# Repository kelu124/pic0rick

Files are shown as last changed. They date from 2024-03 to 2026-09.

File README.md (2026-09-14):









# the _pic0rick_ project




The pic0rick is a very central board for an ultrasound pulse-echo system. It is composed of a main board, based on the RP2040 (or RP2350) and easy to solder SMD, to which a single, and a double PMOD connector can connect to addons:

* The main board is equipped with a 60Msps, 10bit ADC. Front end is protected against high-voltage pulses, and features a proven time-gain compensation system consisting in a AD8331 (7.5 dB to 55.5dB) with a controlling (MCP4812) SPI DAC.
* The single PMOD connector can plug to the Pulser board, which can be equipped with a simple +-25V generation board. Together, they generate the pulse on behalf of the pic0rick main board. The setup can generate three-level pulses ( with a pair of MD1210 + TC6320 ).
* The double PMOD connector can be used for virtually anything. The current code allows for a VGA to be connected, which displays acquisitions from the board.

The current system uses both PIOs (one for the acquisition, the other for the VGA) which leaves the other resources of the rp2040 relatively free to use for your own priorities.

Published documents include:
* KiCad design files for the main board
* KiCad design files for the pulser + hv boards
* KiCad design files for the MUX
* KiCad design files for other boards =)
* rp2040/rp2350 firmware for the microcontroller.

I _know_ the PMODs aren't strictly speaking PMODs, I needed to have 5V facility on the header =)

And if you want to discuss the project - [meet us on our chat](https://matrix.to/#/!dEbJSiragnEvzVBdUa:matrix.org?via=matrix.org).

# Repository layout

| Path | Contents |
|---|---|
| `firmware/` | The unified RP2040/RP2350 firmware (CMake project `adc-pulse`). One source tree with `-DMUX` / `-DDSP` build options. `hw/` = shared acquisition + pulser + spi1 DAC; `dsp/` = RP2350 DSP (CMSIS-DSP Hilbert envelope + binary protocol); `max/` = MAX14866 mux. `version.yaml` + `CHANGELOG.md` track the firmware version; `build.sh` builds all 6 variants into `dist/`. |
| `python/` | Host stack (`pic0rick` package): `device.py` (serial driver), `dsp.py` (binary frame protocol), `ndt_acquisition.py` (echo/thickness analysis + HDF5), and the `example_*.ipynb` notebooks. |
| `hardware/` | KiCad design files and `build.sh` fabrication outputs — main board (`adc/`), pulser + HV (`pulser/`), MUX (`mux/`), VGA (`vga/`), PSRAM (`psram/`). |
| `docs/` | Documentation: `dsp_output_formats.md`, `dsp_test_guide.md`, `images/`, `data/`, `fw_history/` (maintainer-curated reference `.uf2` baselines), and `claude/` (cross-session engineering notes). |
| `.github/workflows/` | CI: builds all firmware variants and publishes a release on push to `main`. |

# Getting Started

## Prerequisites

* pic0rick main board + pulser board + HV board (assembled)
* USB-C cable
* Python 3.9+
* A piezoelectric transducer (e.g. 5 MHz single-element contact probe)

## Building the firmware

The firmware is a single source tree (`firmware/`) with build options:

- **`-DMUX`** (default on) — MAX14866 HV multiplexer support.
- **`-DDSP`** (RP2350/`pico2` only) — on-board Hilbert-envelope DSP + binary
  protocol (see [DSP build](#dsp-build-rp2350) below).

```bash
cd firmware && ./build.sh          # builds all 6 variants into firmware/dist/:
#   rp2040-{mux,nomux}, rp2350-{mux,nomux}, rp2350-{mux,nomux}-dsp
```

Prebuilt `firmware/rp2040.uf2` / `firmware/rp2350.uf2` are the default (mux,
non-DSP) builds. CI publishes all variants as release assets.

## Flashing the firmware

1. Hold the **BOOTSEL** button on the RP2040/RP2350 while connecting USB — the board mounts as a USB mass-storage device. *(After the first flash you can instead send the `reboot-dfu` command over serial to re-enter the bootloader without the button.)*
2. Copy the compiled `.uf2` file into the drive. The board reboots automatically.
3. Verify: open a serial terminal at 115,200 baud. You should see the `run>` prompt (stdio build). Send `version` to confirm the firmware version, board and options.

## Installing the Python library

```bash
pip install pyserial numpy h5py scipy matplotlib
```

Clone this repo and add `python/` to your path, or run notebooks from the `python/` directory.

## Quick start

The examples below target the **DSP build** (`-DDSP`, RP2350) — the recommended
firmware, which streams CRC-checked binary frames. For the plain **stdio build**
see [Serial commands](#serial-commands-stdio--non-dsp-build).

```python
from pic0rick.device import Pic0rick
from pic0rick.ndt_acquisition import UltrasonicAcquisition

probe = Pic0rick()           # auto-detects the USB serial port
print(probe.version()['raw'])

# Set TGC gain (raw DAC value 0–1023; higher = more gain)
probe.set_gain(300)

# Configure and arm the pulser so the capture transmits
probe.configure_pulse(negative_ns=200, damp_ns=2000, positive_ns=200,
                      order="pos-first")
probe.arm_pulser()

frame = probe.read_raw()     # 8000-sample raw ADC frame (CRC-checked)
signal = frame.samples()     # numpy uint16, 0..1023
# envelope = probe.read_fft().samples()   # 4096-sample Hilbert envelope
probe.disarm_pulser()
```

> On the **stdio (non-DSP)** build instead use `probe.dac(gain)`,
> `probe.pulse_adc_trigger(pon, poff, damp)`, `probe.read()`.

Or use the higher-level acquisition wrapper (drives the DSP build for you):

```python
acq = UltrasonicAcquisition.from_probe(
    Fech=60e6,
    pon=70,        # pulse-on duration [ns]
    poff=70,       # pulse-off duration [ns]
    damp=6000,     # damping duration [ns]
    gain=300,      # raw DAC value (0–1023)
    target="1018 steel 25 mm",
    h5_path="my_scan.h5",
)
acq.plot()
```

## Serial commands (stdio / non-DSP build)

The stdio build exposes a text protocol at 115,200 baud (USB CDC), with a `run>`
prompt:

| Command | Arguments | Description |
|---|---|---|
| `start acq <pon> <poff> <damp>` | nanoseconds | Fire pulse, DMA-capture 8000 samples |
| `write dac <N>` | 0–1023 | Set TGC gain (MCP4812 10-bit DAC) |
| `read` | — | Return last captured buffer (hex, comma-separated 10-bit values) |
| `write mux <hex>` | hex word | Write the MAX14866 shift register *(MUX builds)* |
| `set mux` / `clear mux` | — | Pulse the MAX14866 SET / CLR line *(MUX builds)* |
| `version` | — | Print firmware version, board/chip, options, git hash, release URL |
| `reboot-dfu` | — | Reboot into the USB bootloader (BOOTSEL) for reflashing |

> The **DSP build** uses different commands (`dac write`, `read_raw`, `read_fft`,
> …) and a binary protocol — see [DSP build](#dsp-build-rp2350).

### Parameter details

**`pon` / `poff` / `damp`** — expressed in **nanoseconds** from Python. The firmware converts them to 125 MHz clock cycles internally (divides by 8).

**`gain`** — raw 10-bit DAC value (0–1023) controlling the VGAIN pin of the AD8331 TGC amplifier (7.5 dB to 55.5 dB range). The example notebook uses values in the 0–500 range.

### DSP build (RP2350)

Building with `-DDSP=ON` (RP2350/`pico2`) adds an on-board DSP path: a float32
CMSIS-DSP Hilbert envelope. Instead of the text REPL it speaks a binary framed
protocol (64-byte header + CRC32) with two capture modes:

- **`read_raw`** — 8000 raw ADC samples (no FFT).
- **`read_fft`** — 4096-sample Hilbert envelope.

plus `acq raw|envelope|alaw`, `stream start|stop`, `dsp scale|selftest`,
`dac write <0..1023>`, `pulse config <neg_ns> <damp_ns> <pos_ns> <neg-first|pos-first>`,
`pulser arm|disarm`, `status`, `help`, `version`, `reboot-dfu`.

Drive it from Python with `pic0rick.dsp` and these `Pic0rick` methods:
`version()`, `status()`, `set_gain(n)`, `configure_pulse(...)`,
`arm_pulser()`/`disarm_pulser()`, `read_raw()`, `read_fft()`, `capture(payload)`.
The frame and status formats are documented in
[`docs/dsp_output_formats.md`](docs/dsp_output_formats.md); see
[`docs/dsp_test_guide.md`](docs/dsp_test_guide.md) and the
`python/example_dsp.ipynb` / `python/example_simple.ipynb` notebooks.

## Signal chain

```
Transducer
   │
   ├──► TX path: PIO pulser GPIO11/12 (P+/P-) + GPIO16/17 (PDAMP/OE) → MD1213 + TC6320 → ±25V three-level pulse
   │
   └──► RX path: T/R protection → AD8331 TGC (gain set by MCP4812 DAC)
                  → 60 Msps 10-bit ADC (PIO + DMA, 8000 samples/acquisition)
                  → USB CDC → Python
```

The ADC samples are 10-bit unsigned (0–1023, mid-scale = 512). The `ndt_acquisition` wrapper normalises them to float32 in the range ≈ [−1, 1]:

```python
signal = (adc_count - 512) / 512.0
```

# Setup

## The three boards assemble look like this

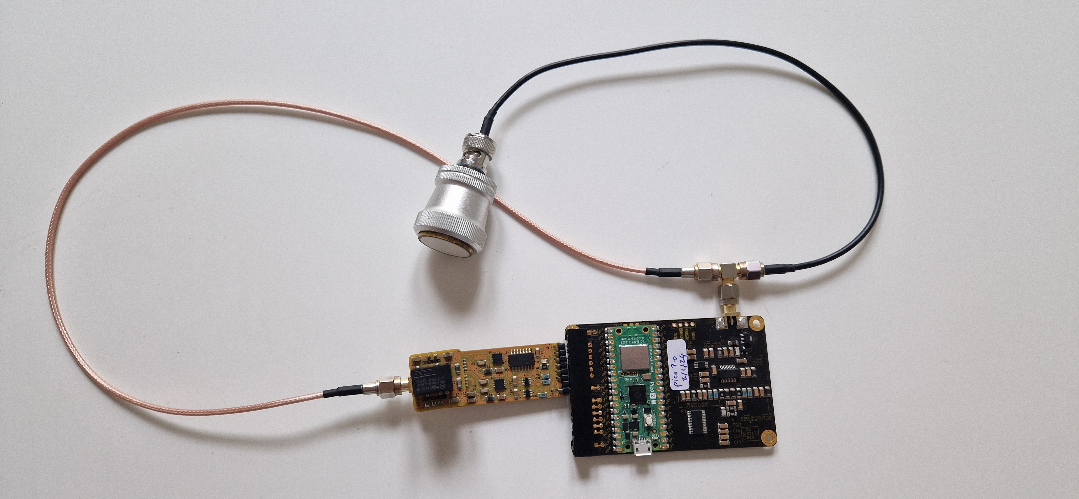
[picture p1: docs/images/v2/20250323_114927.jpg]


## Example of acquisitions

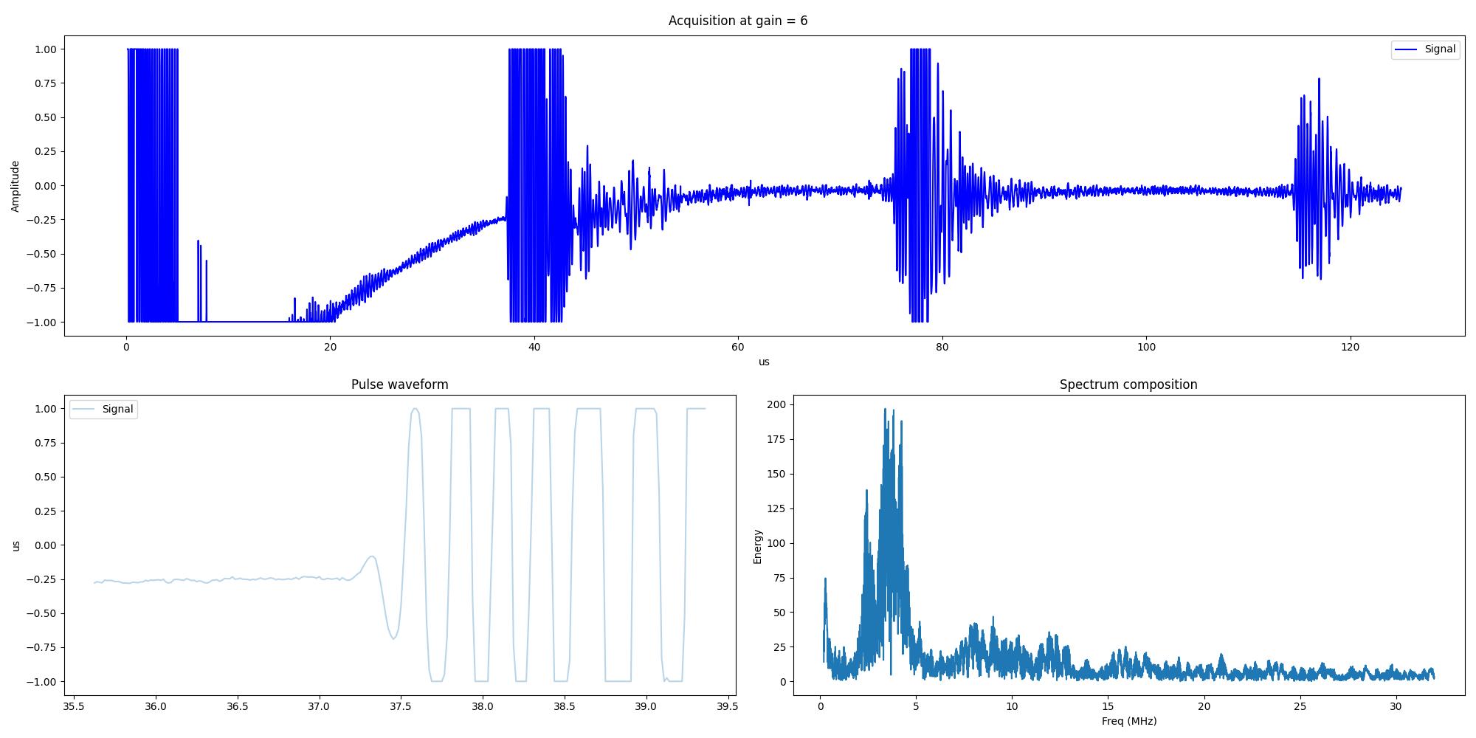
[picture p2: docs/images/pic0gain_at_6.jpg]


## Demo of output to VGA 

Beware. This is not a standard development, more of a proof of concept. It lives on a [separate branch here](https://github.com/kelu124/pic0rick/tree/VGA).

Only using the pico to setup gain and trigger acquisitions. The screen displays the gain value (0 to 9, with a 100x divider). Displays raw buffer of acquisition.

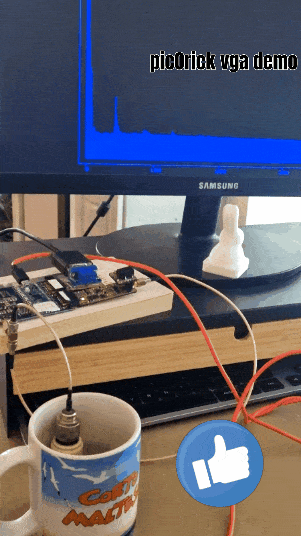
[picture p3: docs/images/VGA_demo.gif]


## Example of a compact assembly 

Within a game card footprint

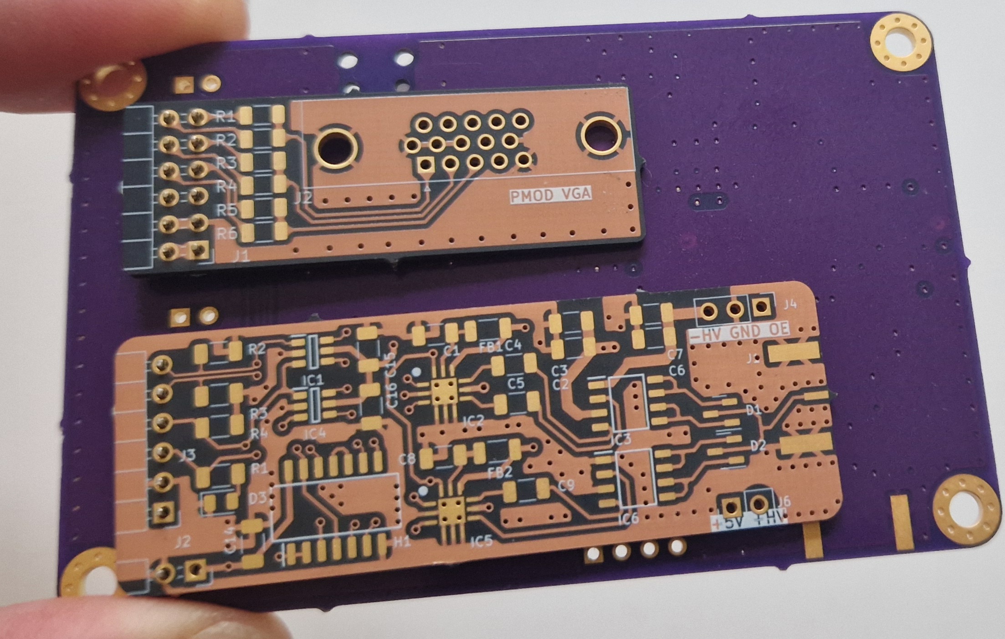
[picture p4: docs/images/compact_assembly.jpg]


# Along with the other boards

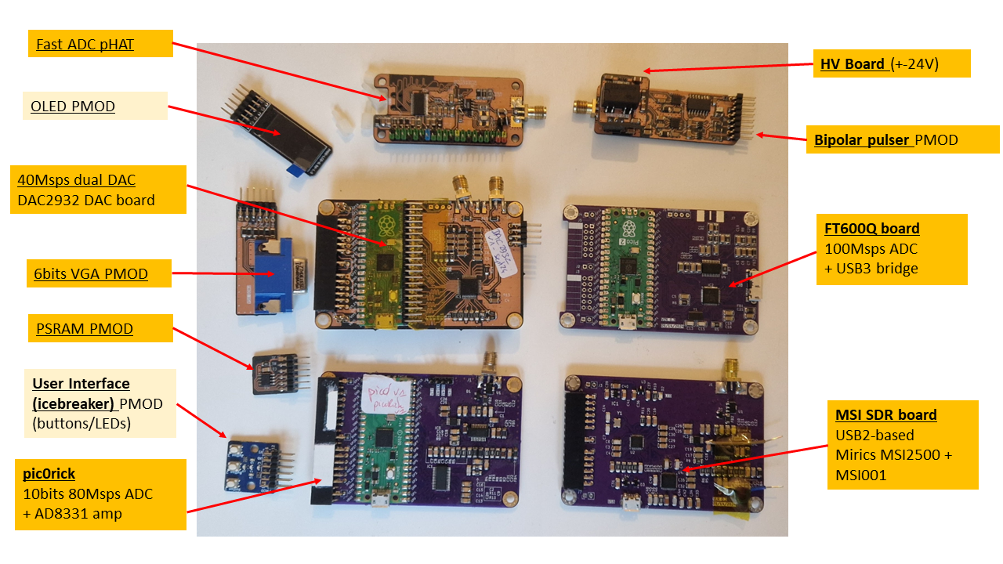
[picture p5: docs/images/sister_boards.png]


# Assembly

## What you get :

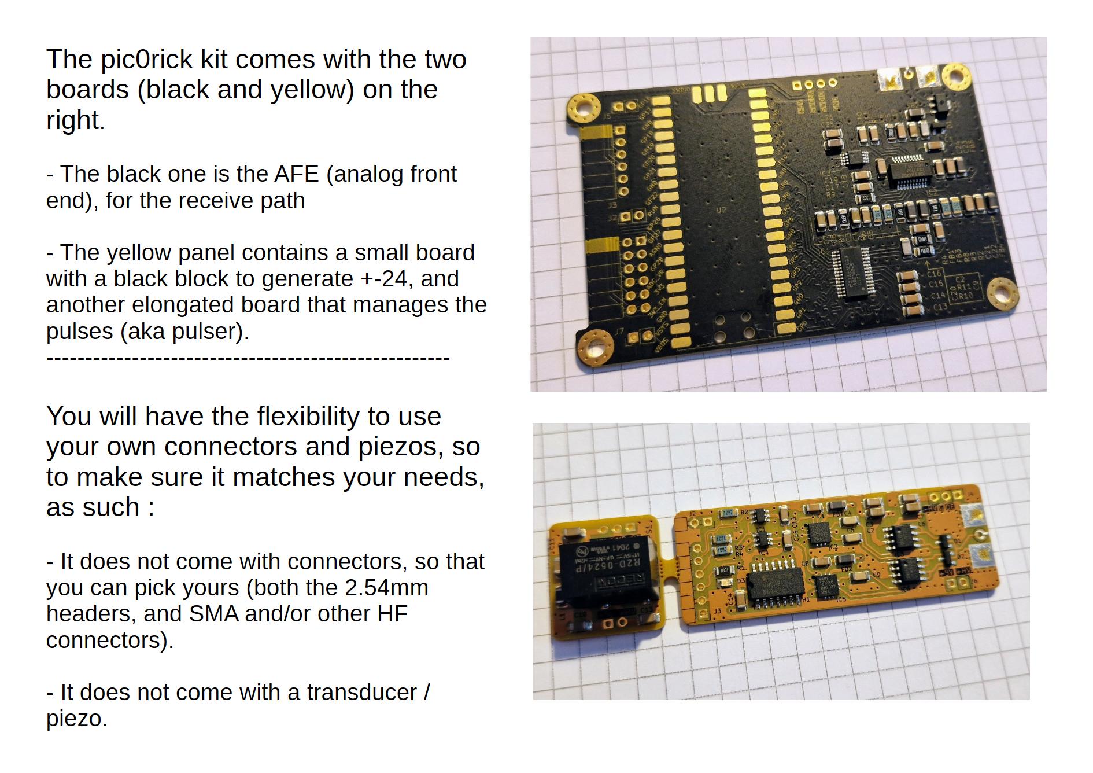
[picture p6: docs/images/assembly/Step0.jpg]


## Before assembly

You will need to get a few headers, a raspberry pico, and SMA connectors

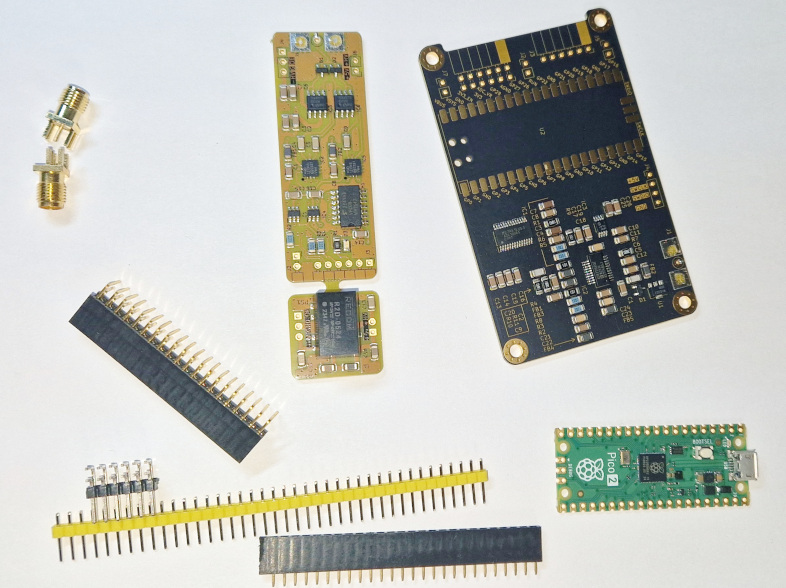
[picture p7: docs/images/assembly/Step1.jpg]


## Focus on the Pulser connector

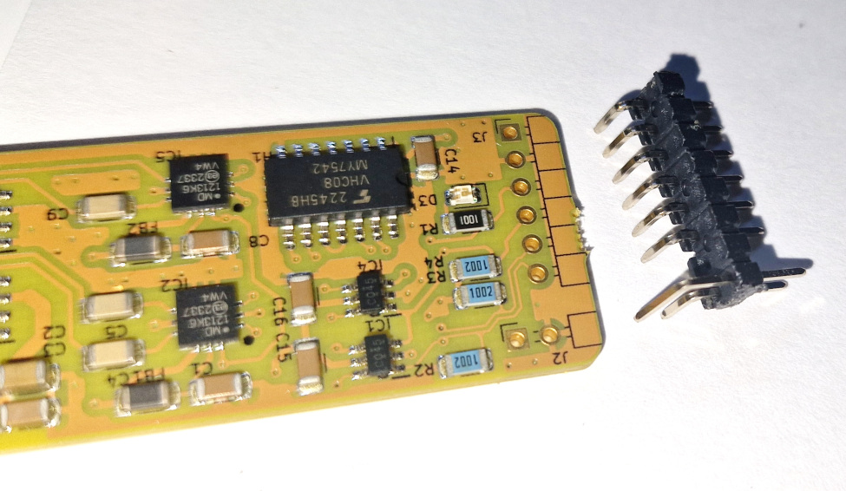
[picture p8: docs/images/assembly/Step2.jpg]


## Once assembled

### Top view

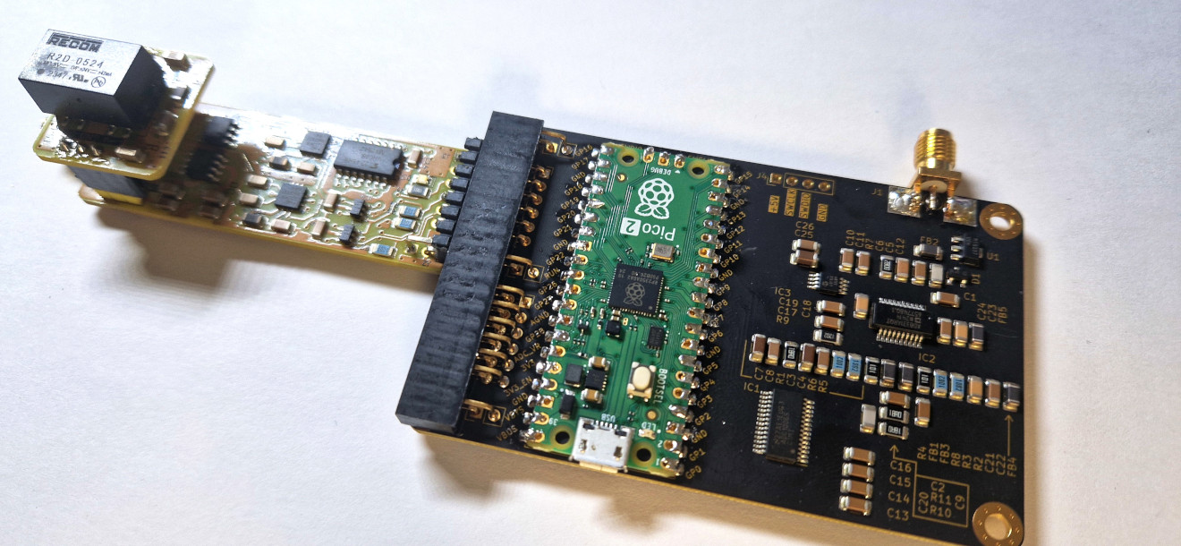
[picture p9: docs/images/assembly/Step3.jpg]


### Bottom view 

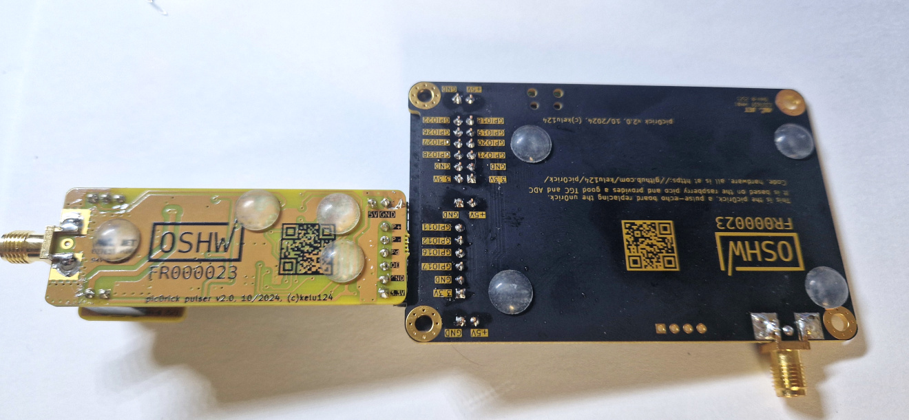
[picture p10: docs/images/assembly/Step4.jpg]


# License

This work is based on three previous TAPR projects, [the echOmods project](https://github.com/kelu124/echomods/), the [un0rick project](https://doi.org/10.5281/zenodo.377054), and the [lit3rick project](https://doi.org/10.5281/zenodo.5792245) - their boards are open hardware and software, developped with open-source elements as much as possible.

Copyright Luc Jonveaux (<kelu124@gmail.com>) 2024

* The hardware is licensed under TAPR Open Hardware License (<www.tapr.org/OHL>)
* The software components are free software: you can redistribute it and/or modify it under the terms of the GNU General Public License as published by the Free Software Foundation, either version 3 of the License, or (at your option) any later version.
* The docs is licensed under a [Creative Commons Attribution-ShareAlike 3.0 Unported License](http://creativecommons.org/licenses/by-sa/3.0/).

## Disclaimer

This project is distributed WITHOUT ANY EXPRESS OR IMPLIED WARRANTY, INCLUDING OF MERCHANTABILITY, SATISFACTORY QUALITY AND FITNESS FOR A PARTICULAR PURPOSE.

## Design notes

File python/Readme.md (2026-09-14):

# pic0rick — Python host tools

Host-side Python for driving a pic0rick over USB serial and turning its raw
ADC traces into ultrasonic NDT (non-destructive testing) measurements: pulse
tuning, gain sweeps, back-wall echo detection, thickness estimation, and HDF5
storage.

> Works with both firmware builds from `firmware/`:
> - the **stdio (non-DSP)** build's text REPL (`write dac`, `start acq`, `read`),
>   used by `Pic0rick.dac/pulse_adc_trigger/read`;
> - the **DSP (`-DDSP`, RP2350)** build's binary frame protocol, via
>   `pic0rick.dsp` and `Pic0rick.status/capture/read_fft/read_raw`.

## Layout

```
python/
├── pic0rick/
│   ├── device.py            # Pic0rick — serial driver for the board
│   └── ndt_acquisition.py   # UltrasonicAcquisition — capture + analysis + HDF5
├── example_acquisition.ipynb  # live-hardware workflow (needs a board)
└── example_process.ipynb      # offline analysis of a saved HDF5 (no hardware)
```

## Python modules

### `pic0rick/device.py` — the hardware driver
`Pic0rick` opens the CDC serial port (115200 baud; `_find_port()` auto-detects
`/dev/ttyACM*`·`/dev/ttyUSB*` on Linux, `COM*` on Windows, `tty.usbmodem*` on
macOS) and wraps the firmware's three text commands:

| Method | Firmware command | Purpose |
|---|---|---|
| `dac(N)` | `write dac N` | Set the DAC (drives the analog gain / VGA). |
| `pulse_adc_trigger(pon, poff, damp)` | `start acq …` | Fire the pulser and capture a trace. |
| `read()` | `read` | Return the captured samples (comma-separated hex text). |

`Fech = 60e6` (60 MS/s) is stored on the instance. `verbose`/`logging` options
echo or append the raw serial exchange to a log file.

### `pic0rick/ndt_acquisition.py` — capture + analysis + storage
The workhorse. Importing `pic0rick.device` is **lazy** (via `get_probe()`), so
this module is fully usable for offline analysis on a machine with no hardware.

- **`UltrasonicAcquisition`** — a dataclass bundling one trace with its metadata
  (`Fech`, `pon/poff/damp`, `gain`, `target`, transducer `piezo_*`). Key members:
  - `from_probe(...)` — trigger the board (`dac` → `pulse_adc_trigger` → `read`),
    decode the hex samples to a normalized `[-1, 1]` signal (`(code-512)/512`),
    and optionally cache to HDF5 keyed on `(gain, pon, poff, damp, target,
    piezo_id)` (a cache hit skips the hardware).
  - `signal_filtered` — zero-phase Butterworth band-pass around the probe's
    centre frequency/bandwidth.
  - `detect_echoes(...)` — rectify + smooth, find the main echo in a time
    window, then track periodic back-wall echoes at `Δt = 2·thickness/c`;
    returns peak times/amplitudes, a measured `Δt`, a back-computed thickness,
    and a labelled figure.
  - `calibrate(...)` — sweep `pon = poff`, save every shot, and report the pulse
    width that maximises the windowed echo amplitude (with a 3-panel figure).
  - `amplitude(...)`, `plot(...)`, `label(...)`, `info(h5_path)`.
- **HDF5 I/O** — `save_h5`, `load_h5`, and per-acquisition `save()`; each trace
  is a group with the signal dataset (gzip) plus scalar attributes, deduplicated
  by the same key.

## Notebooks

### `example_acquisition.ipynb` — live hardware
End-to-end workflow against a connected board and a 1018-steel 5-step
calibration block with a 5 MHz probe: gain sweeps, `calibrate()` for the best
`pon/poff`, then `from_probe()` + `detect_echoes()` at several block thicknesses
(10/15/25 mm) to recover thickness from the echo train, and `info()` to
summarize the stored HDF5.

### `example_process.ipynb` — offline analysis
No hardware: `load_h5(...)` a saved capture, extract the emitted pulse, and study
it (autocorrelation / side-lobe structure) with NumPy/SciPy. Good starting point
for signal-processing work on existing data.

## Dependencies

`pyserial`, `numpy`, `scipy`, `h5py`, `matplotlib`. (No `requirements.txt` here
yet — install those into your environment.)

## Example data

The notebooks read `../docs/data/calibration_block_5steps_1018steel.h5`.

## Quick start (offline)

```python
from pic0rick.ndt_acquisition import load_h5
acqs = load_h5("../docs/data/calibration_block_5steps_1018steel.h5")
acqs[0].plot()          # raw (+ filtered if piezo_* set)
```

Live capture instead:

```python
from pic0rick.ndt_acquisition import UltrasonicAcquisition
a = UltrasonicAcquisition.from_probe(Fech=60e6, gain=350, pon=70, poff=70, damp=6000,
                                     piezo_central_freq=5e6, piezo_bandwidth=4e6)
a.detect_echoes(start_us=35, end_us=55, target_thickness=0.010, speed_of_sound=5950)
```

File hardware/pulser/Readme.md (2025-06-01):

# Pulser hardware file

This folder contains the newest version of pulser and HV board, with breakbout

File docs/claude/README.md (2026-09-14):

# Claude handoff notes — pic0rick

This folder holds durable, cross-session notes for Claude Code instances working
in this repository. If you are a new instance, **read this first**, then the
topic files listed below. Keep these notes updated when you learn something a
future instance would waste time rediscovering.

- `firmware.md` — the repo-root `firmware/` folder: the original mainline
  `adc-pulse` Pico firmware (uses the MAX14866; RP2040 + RP2350 builds).
- `onboard-dsp-firmware.md` — **retired**: the old `experiments/onboard_dsp/`
  firmware is now the mainline `-DDSP` build (`firmware/dsp` + `firmware/hw`);
  this note is now a pointer to where everything went.
- `dsp_output_formats.md` (in `docs/`, not here) — the DSP binary frame / status
  format reference (moved from onboard_dsp's `understanding_figures.md`).
- `python-host-tools.md` — the repo-root `python/` NDT stack (serial driver +
  echo/thickness analysis + HDF5) that drives the mainline firmware.
- `hardware-build.md` — `hardware/build.sh`: KiBot + kicad-cli production
  outputs (gerbers/CPL/BOM/STEP + 3D renders), build groups incl. the fast
  `fab-fast` path, and the venv/3D-model gotchas.
- `hardware-testing.md` — flashing a connected board (UF2 → BOOTSEL mass storage)
  and talking to the REPL over `/dev/ttyACM0`; the `reboot-dfu` iterate loop.

## `docs/fw_history/` — maintainer-only firmware baselines

`docs/fw_history/` holds known-good reference `.uf2` binaries (regression
baselines). **Claude must never add/copy/build/commit `.uf2` files there** — only
the maintainer curates them. Claude may edit its README and *flash* them for
diagnostics. Claude build output goes to `firmware/dist/` (gitignored) + releases.

## Task tracking & commit logs

- `TODO.md` — open, actionable items (with owner tags). `DONE.md` — completed.
  Move items from one to the other as they finish.
- `commits/` — one log file per commit (`<YYYY-MM-DD>-<slug>.md`) recording what
  changed and why. **Add a log entry for every commit you make in this repo.**
- Any new remark/discovery that needs an action goes in `TODO.md`.

## Versioning rule

Firmware and the Python library each carry `A.B.C` in their own `version.yaml`
(`firmware/version.yaml`, `python/pic0rick/version.yaml`).
- **Claude bumps only the patch (C)** — firmware patch on changes to `firmware/`
  files, python patch on changes to `python/` files (independent). A/B 0-99,
  C 0-999. **The maintainer owns major/minor — never change them.**
- Always update that file's one-line, double-quoted `changes:` summary; the CI
  release body and the firmware `version` command read it.
- **On every firmware version bump, add a matching entry to
  `firmware/CHANGELOG.md`** (`## A.B.C — YYYY-MM-DD`, newest first). `version.yaml`
  and `CHANGELOG.md` are the version record — editing only those does not trigger
  a bump.

> These are working memories, not authoritative docs. Verify a claim against the
> code before relying on it — file/line references can drift.

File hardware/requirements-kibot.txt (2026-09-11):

# KiBot production-output toolchain — pinned dependencies for hardware/.venv-kibot
#
# WHY A SEPARATE VENV?
#   KiCad's Python bindings (`pcbnew`) and `wx` are compiled C-extensions that
#   ship only for the *system* Python (3.10 on this Ubuntu 22.04 box, installed
#   by the `kicad` apt package). The repo's root .venv is Python 3.11 via pyenv,
#   so it can never import pcbnew. KiBot needs pcbnew, hence a dedicated venv.
#
# HOW TO (RE)CREATE IT  (hardware/build.sh does this automatically):
#   cd hardware
#   /usr/bin/python3 -m venv --system-site-packages .venv-kibot
#   #   ^ system Python 3.10  ^ so pcbnew + wx from the kicad apt pkg are visible
#   .venv-kibot/bin/pip install --upgrade pip
#   .venv-kibot/bin/pip install --no-compile -r requirements-kibot.txt
#   #   ^ --no-compile is REQUIRED: KiBot's import-time macro system fails when
#   #     its modules are byte-compiled by pip.
#
# SYSTEM PREREQUISITES (apt):
#   kicad kicad-footprints kicad-symbols kicad-packages3d   # provides kicad-cli + pcbnew + 3D models
#   python3-wxgtk4.0                                         # wx, required by KiBot at startup
#
# NOTE: the schematic PDF is produced with `kicad-cli` directly (see build.sh),
#       not KiBot's KiAuto backend, so no X display / xvfb is needed.

kibot
kiauto                 # KiBot helper backends (kicad2step_do, etc.)
InteractiveHtmlBom     # interactive HTML BOM generator (ibom output)

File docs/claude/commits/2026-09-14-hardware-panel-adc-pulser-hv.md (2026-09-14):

# 2026-09-14 — hardware: register panel_adc_pulser_hv in build.sh

Branch `feature/unify-firmware-dsp`.

## What
- Added `panel_adc_pulser_hv` to the `BOARDS` registry in `hardware/build.sh`
  so `./build.sh all` includes it.
- New board folder `hardware/panel_adc_pulser_hv/` (`3_in_1_Panel.kicad_pcb` +
  `.kicad_sch`, 4-layer: F/B + In1/In2).
- Generated production outputs under
  `hardware/panel_adc_pulser_hv/build_jlcpcb/` (same layout as the other
  boards, which keep their build outputs in git).

## Why
User: include panel_adc_pulser_hv in build.sh and run it.

## Verified
`./build.sh panel_adc_pulser_hv` (group `all`) completed cleanly — schematic
present, so full set built:
- gerbers (4 copper layers, mask, silk, edge cuts, PTH/NPTH drills)
- production `3_in_1_Panel-JLCPCB-gerbers.zip`
- assembly JLCPCB BOM + CPL (CSV)
- docs schematic PDF + interactive iBOM HTML
- 3D STEP + top/bottom PNG renders
KiBot exited 0 (no warnings); both renders succeeded.

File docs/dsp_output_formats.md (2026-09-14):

# Understanding the pic0rick firmware outputs

This note explains every output the RP2350A envelope/A-law firmware produces on
its USB-CDC link, so a human (or the capture tool) can read them without diving
into the C sources. It covers:

1. The two kinds of output (text lines vs. binary frames).
2. The `status` line, field by field.
3. The other text responses (`help`, per-command `OK`, `ERR` codes).
4. The 64-byte binary frame header and payloads.
5. The self-test output.

All field definitions come straight from the firmware: `main.c` (`send_status`,
`send_help`, command handlers), `u4rk.h` (constants), `dsp.c` (DSP stages),
`pipeline.c` (drop accounting) and `protocol.c` (`u4rk_serialize_header`).

---

## 1. Two output channels on one CDC port

The firmware never mixes the two:

- **Text mode** — every reply is a single CRLF-terminated line starting with
  `OK ` or `ERR `. This is what you get for `status`, `help`, `dac`, `pulse`,
  `dsp scale`, and the acknowledgement of `acq` / `stream start`.
- **Binary mode** — after an `acq`/`stream start`/`dsp selftest` is
  acknowledged with an `OK`, the firmware emits one or more fixed-layout
  binary **frames** (64-byte header + payload). No text is interleaved while
  frames are in flight; a stream is closed with `stream stop`, which returns to
  text mode with a final `OK stream stopped drops=N`.

---

## 2. The `status` line

Example (all on one line):

```
OK board=pic0rick package=RP2350A firmware=1.6 dsp_backend=f32-rfft-hilbert
   samples=4096 sample_rate=60000000 pulser=disarmed pulse=96/6000/96/pos-first
   dac=1023 scale=512.000 stream=off/1 drops=0
   stages_us=538/4392/137/4751/1066/689 dsp_us=11579 worst_us=12069
   performance=over-budget envelope_max_rate=50 alaw_max_rate=70 cmsis=1.17.0
```

It is a space-separated list of `key=value` tokens. Field by field:

| Token | Example | Meaning |
|---|---|---|
| `board` | `pic0rick` | Fixed board family string. |
| `package` | `RP2350A` | MCU package this build targets (Pico 2 / RP2350A). Fixed literal. |
| `firmware` | `1.6` | Firmware version (`pico_set_program_version` in `CMakeLists.txt`). The capture tool refuses any other value. |
| `dsp_backend` | `f32-rfft-hilbert` | Envelope algorithm: float32 real-FFT Hilbert transform on the Cortex-M33 FPU. Fixed literal. |
| `samples` | `4096` | Samples per acquisition (`U4RK_SAMPLE_COUNT`). |
| `sample_rate` | `60000000` | ADC sample rate in **Hz** (60 MS/s, `U4RK_SAMPLE_RATE_HZ`). |
| `pulser` | `disarmed` | `armed` or `disarmed`. A capture only fires the pulser when armed. |
| `pulse` | `96/6000/96/pos-first` | Pulser timing: `negative_ns / damp_ns / positive_ns / order`. `order` is `neg-first` or `pos-first`. Durations are the *actual* values after rounding to the 8 ns PIO tick. |
| `dac` | `1023` | Last value written to the MCP4812 DAC (0–1023, 10-bit code). Boots at 0. |
| `scale` | `512.000` | A-law full-scale reference in **ADC counts** (`dsp scale`). Envelope values at/above this map to A-law 255; default 512. |
| `stream` | `off/1` | `state/rate_hz`. `state` is `on` or `off`; `rate_hz` is the last requested stream rate. |
| `drops` | `0` | Cumulative dropped frames since boot (`processing_drops + usb_drops`, see §2.2). |
| `stages_us` | `538/4392/137/4751/1066/689` | Per-stage time of the **last DSP frame**, in **microseconds** (see §2.1). |
| `dsp_us` | `11579` | Total time of the last DSP frame, in µs. |
| `worst_us` | `12069` | Worst-case total DSP time observed, in µs (running maximum in `dsp.c`). |
| `performance` | `over-budget` | `ok` if `worst_us <= 4500`, else `over-budget` (`U4RK_DSP_TARGET_US = 4500`). |
| `envelope_max_rate` | `50` | Max accepted `stream` rate for `envelope`, in Hz. |
| `alaw_max_rate` | `70` | Max accepted `stream` rate for `alaw`, in Hz. |
| `cmsis` | `1.17.0` | CMSIS-DSP library version compiled in. |

> Raw's max stream rate (100 Hz, `U4RK_RAW_MAX_RATE_HZ`) is **not** printed in
> the status line — only `envelope_max_rate` and `alaw_max_rate` are.

### 2.1 The six DSP stages (`stages_us`)

The order is fixed: **`preprocess / forward_fft / mask / inverse_fft / magnitude / alaw`**.
They correspond one-to-one to the blocks in `u4rk_dsp_envelope()`:

| # | Stage | What happens |
|---|---|---|
| 1 | `preprocess` | Unpack the 10-bit ADC samples (`(dma >> 1) & 0x3FF`), compute the DC mean, subtract it. |
| 2 | `forward_fft` | 4096-point float32 real FFT (`arm_rfft_fast_f32`, forward). |
| 3 | `mask` | Build the analytic-signal spectrum: multiply the packed half-spectrum by `-j`. |
| 4 | `inverse_fft` | Inverse real FFT to recover the Hilbert (quadrature) component. |
| 5 | `magnitude` | `sqrt(real² + quadrature²)` per sample → the envelope; also tracks the peak. |
| 6 | `alaw` | A-law compression of the envelope (only for A-law frames; `0` otherwise). |

**Raw and legacy captures skip the FFT entirely** (they only run `preprocess`),
so after a raw/legacy capture the status reports `stages_us=0/0/0/0/0/0`,
`dsp_us=0`, and `worst_us=0`. The values persist from the *last DSP frame*, so a
plain `status` query reflects whatever job most recently completed. `worst_us`
is a running maximum kept inside the envelope backend, so it re-appears (largest
value seen since boot) after the next envelope/A-law frame.

### 2.2 Drop accounting (`drops`)

`drops` is the sum of two cumulative-since-boot counters:

- **processing drops** — a capture could not get a buffer/output slot, a DSP
  result could not be queued, or a frame was discarded during `stream stop` /
  DMA-fault cleanup.
- **USB drops** — a completed frame could not be sent to the host (transfer
  failed, or the CDC session closed with work still queued).

For a healthy stream the acceptance criterion is `drops=0`.

---

## 3. Other text responses

### `help`

One line listing every command (used by the tool to confirm there is **no**
MAX14866/mux command):

```
OK commands=status|help|pulser arm|pulser disarm|pulse config <negative_ns> <damp_ns> <positive_ns> <neg-first|pos-first>|dac write <0..1023>|dsp scale <reference>|dsp selftest|acq <raw|envelope|alaw>|stream start <raw|envelope|alaw> <rate_hz>|stream stop|start acq|read
```

### Per-command `OK` acknowledgements

| Command | Success reply |
|---|---|
| `pulser arm` / `pulser disarm` | `OK pulser armed` / `OK pulser disarmed` |
| `pulse config N D P order` | `OK pulse=N/D/P/order` (actual, tick-rounded values) |
| `dac write V` | `OK dac=V` |
| `dsp scale R` | `OK scale=R` |
| `dsp selftest` | `OK selftest frames=21 cases=7` (then 21 binary frames) |
| `acq <type>` | `OK capture started type=<type>` (then 1 binary frame) |
| `stream start <type> <rate>` | `OK stream started type=<type> rate=<rate>` (then binary frames until `stream stop`) |
| `stream stop` | `OK stream stopped drops=N` (or `OK stream already stopped` if not streaming) |
| `start acq` (legacy) | `OK legacy acquisition started` |
| `read` (legacy) | `OK raw-hex 4096` followed by 4096 comma-separated 3-hex-digit samples |

### `ERR` codes

Failures are `ERR <code> <message>`:

| Code | Meaning |
|---|---|
| `BUSY` | An operation is already in progress (no free buffer / pipeline busy). |
| `ARG` | Malformed arguments (bad type, missing/extra token, bad order keyword). |
| `RANGE` | Value out of range (DAC not 0–1023, scale not in (0, 65535], pulse below the 40 ns floor). |
| `RATE` | Requested stream rate outside `1..max` for that payload type. |
| `DMA` | Acquisition timed out; the pulser is disarmed. |
| `COMMAND` | Unknown command. |
| `LINE` | Command line too long. |
| `NO_DATA` | `read` issued before any acquisition completed. |

---

## 4. Binary frames

Every acquisition/stream/self-test result is a **64-byte little-endian header**
followed by its payload. Layout (from `u4rk_serialize_header`):

| Offset | Size | Field | Notes |
|---:|---:|---|---|
| 0 | 4 | magic | ASCII `P0RK` |
| 4 | 1 | protocol version | `1` |
| 5 | 1 | payload type | `1`=raw, `2`=envelope, `3`=A-law |
| 6 | 2 | flags | bitfield, see below |
| 8 | 4 | sequence | monotonic frame counter |
| 12 | 4 | sample count | `4096` |
| 16 | 4 | sample rate | `60000000` Hz |
| 20 | 4 | payload bytes | `8192` raw / `16384` envelope / `4096` A-law |
| 24 | 8 | capture timestamp | µs since boot (self-test: the case index) |
| 32 | 4 | ADC DC mean | float32, mean of the raw samples |
| 36 | 4 | envelope peak | float32, max envelope amplitude (0 for raw) |
| 40 | 4 | A-law reference | float32, the `scale` used for this frame |
| 44 | 4 | pulse negative_ns | uint32 |
| 48 | 4 | pulse damp_ns | uint32 |
| 52 | 4 | pulse positive_ns | uint32 |
| 56 | 4 | dropped frames | cumulative drops at frame time |
| 60 | 4 | payload CRC32 | IEEE CRC32 of the payload only |

### Payload types

| Type | dtype | Bytes | Content |
|---|---|---|---|
| `1` raw | `uint16` LE | 8192 | 10-bit ADC codes (0–1023). |
| `2` envelope | `float32` LE | 16384 | Hilbert envelope amplitude in ADC counts. |
| `3` A-law | `uint8` | 4096 | A-law-compressed positive envelope (A = 87.6). |

### Flags (offset 6)

| Bit | Name | Meaning |
|---:|---|---|
| 0 | `ALAW_SATURATED` | An A-law sample hit the `scale` ceiling and was clipped. |
| 1 | `PROCESSING_DROP` | At least one processing drop has occurred since boot. |
| 2 | `USB_DROP` | At least one USB drop has occurred since boot. |
| 3 | `SELFTEST` | This frame is a deterministic self-test vector. |
| 4 | `PULSER_ARMED` | The pulser was armed for this capture. |
| 8–15 | self-test case | For self-test frames, the case index (0–6) lives in the high byte. |

So a self-test A-law frame for case 2 (`sinusoid`) that saturated would show
`flags = 0x0209` (`0x0200` case=2, `0x08` SELFTEST, `0x01` ALAW_SATURATED).

---

## 5. Self-test output

`dsp selftest` (or the tool's `--selftest`) emits **21 frames = 7 cases × 3
payload types** (raw, envelope, A-law), in that order per case. The 7 cases are:

| Case | Name | Signal |
|---:|---|---|
| 0 | `zero` | all zero |
| 1 | `dc` | constant 700 |
| 2 | `sinusoid` | 32-cycle sine |
| 3 | `am` | amplitude-modulated tone |
| 4 | `two-bursts` | two windowed bursts |
| 5 | `impulse` | single spike at the midpoint |
| 6 | `clipping` | full-scale square wave |

The PC tool validates each case against `scipy.signal.hilbert` and prints, per
case:

```
sinusoid     nrms=8.389e-08 peak_delta=0 alaw_delta=0
```

- `nrms` — normalized RMS error of the envelope (pass ≤ `1e-4`).
- `peak_delta` — envelope peak-index difference in samples (pass ≤ 1).
- `alaw_delta` — max A-law byte-level difference vs. the reference (pass ≤ 1).

---

## Parsing helpers

The host library `python/pic0rick/dsp.py` parses this protocol:

- `pic0rick.dsp.FrameReader(port).read_frame()` → a `Frame` (header + payload;
  CRC-checked; `.samples()` decodes to a numpy array). Length-agnostic:
  `read_raw` (8000) and `read_fft` (4096) both parse.
- `pic0rick.dsp.parse_status(line)` → a typed `dict` (with `pulse`, `stream`,
  `stages_us` broken out as sub-dicts).
- `pic0rick.dsp.describe_status(line_or_dict)` → a human-readable multi-line
  summary (parameters + per-stage DSP µs times).

From the device driver: `Pic0rick.status()`, `.read_fft()`, `.read_raw()`,
`.capture(payload)` (see `docs/claude/python-host-tools.md`).

> This spec was written for the retired `experiments/onboard_dsp/` firmware; that
> firmware is now the mainline `-DDSP` build (`firmware/dsp` + `firmware/hw`).
> The formats are unchanged except that `sample_count` is now per-mode.

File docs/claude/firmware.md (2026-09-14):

# firmware/ (root) — working notes

Scope: the repo-root **`firmware/`** folder — the **unified** pic0rick Pico
firmware (CMake project `adc-pulse`). One tree with build variants: `-DMUX`
(MAX14866 mux, default on) and `-DDSP` (RP2350 Hilbert-envelope DSP + binary
protocol, off by default). The former `experiments/onboard_dsp/` firmware was
merged in here on 2026-09-13 (see `onboard-dsp-firmware.md`).

## First-glance layout

```
firmware/
├── main.c              # stdio REPL (non-DSP builds) + command dispatch
├── main_dsp.c          # raw-TinyUSB command loop (-DDSP builds)
├── CMakeLists.txt      # project adc-pulse; -DDSP / -DMUX / PICO_BOARD toggles
├── build.sh            # builds all 4 non-DSP variants into dist/
├── version.yaml        # single source of truth for the version
├── hw/                 # SHARED, USB-free drivers (both builds)
│   ├── acquisition.c/.h/.pio   # ADC capture + pulser (u4rk_*)
│   ├── pulser.pio              # 4-pin pulser (P+/P-/PDAMP/OE)
│   ├── dac.c/.h                # spi1 MCP4812 gain DAC (u4rk_dac_*)
│   └── u4rk.h                  # pins, sample counts, protocol structs
├── dsp/                # DSP-only (-DDSP): dsp/pipeline/protocol + raw TinyUSB
│   ├── dsp.c/.h pipeline.c/.h protocol.c/.h
│   └── usb_transport.* usb_descriptors.c tusb_config.h
├── max/                # MAX14866 HV mux driver (SPI bit-bang via PIO)
│   ├── max14866.c / max14866.h / max14866.pio
├── rp2040.uf2 / rp2350.uf2   # prebuilt (mux, non-DSP) defaults
└── build*/ dist/       # build trees / outputs (gitignored)
```

## What it does

USB-CDC serial **text REPL** (via `stdio_usb`, not a raw binary protocol like
onboard_dsp). On boot it waits for a USB connection, inits ADC → DAC → MAX14866,
then loops printing a `run> ` prompt and reading a line. `main.c`'s
`command_list` maps text to handlers:

| Command | Handler | Purpose |
|---|---|---|
| `start acq [pon] [poff] [damp]` | `start_acq_cmd` | Configure+arm shared pulser, capture 8000 samples |
| `read` | `read_cmd` | Dump the captured 8000 ADC samples (hex) |
| `write dac <v>` | `write_dac_cmd` | Write the gain DAC (MCP4812, spi1) |
| `version` | `version_cmd` | Print version, changes, board/chip, mux, git hash, release URL |
| `reboot-dfu` | `reboot_dfu_cmd` | Reboot into the USB bootloader (BOOTSEL) via `reset_usb_boot` |
| `write mux <v>` | `max14866` | Write the MAX14866 mux word *(MUX builds only)* |
| `set mux` | `max14866_set` | MAX14866 SET *(MUX builds only)* |
| `clear mux` | `max14866_clear` | MAX14866 CLEAR *(MUX builds only)* |

Parsing is whitespace `strtok` (command + subcommand + rest-as-args); a missing
arg defaults to `"0"`. Unknown input prints `Unknown command: ...`. Output is
human-oriented `printf` text, not framed binary.

## Key constants

- `hw/u4rk.h`: `U4RK_SAMPLE_COUNT 4096` (FFT), `U4RK_RAW_SAMPLE_COUNT 8000`
  (raw), sample rate 60 MHz; pins: ADC clk 0 / data 1–10, DAC CS/SCK/MOSI
  13/14/15, pulser P+ 11 / P- 12 / PDAMP 16 / OE 17.
- `hw/acquisition.c`: ADC PIO 120 MHz, pulse PIO 125 MHz, 8 ns tick (min 5),
  2 ms DMA timeout.
- `max/max14866.h`: SPI bit-bang pins `DIN 18`, `SCLK 19`, `LE 20`, `SET 21`,
  `CLR 28`, `MAX14866_CLK 2 MHz`.

## Build / flash

```
cd firmware && ./build.sh          # builds SIX variants into firmware/dist/:
#   rp2040-mux, rp2040-nomux, rp2350-mux, rp2350-nomux    (stdio / non-DSP)
#   rp2350-mux-dsp, rp2350-nomux-dsp                      (raw-TinyUSB DSP)
#   + copies the two rp2350/rp2040 mux non-DSP builds to rp2040.uf2 / rp2350.uf2
# DSP builds share one CMSIS-DSP clone in firmware/.deps (gitignored).
```
- SDK **2.3.0**, toolchain **14_2_Rel1** (per CMakeLists; bumped from 2.2.0 in
  fw v0.1.3 on the unify branch — needed for the onboard-DSP/CMSIS-DSP merge).
  SDK resolved via the pico-vscode cmake include, else `PICO_SDK_PATH` (that's
  what CI uses; the workflow checks out pico-sdk `2.3.0`).
- `PICO_BOARD` defaults to `pico` (RP2040) if not passed.
- **`-DMUX=ON` (default) / `-DMUX=OFF`** toggles the MAX14866 mux module. It
  gates `max/max14866.c` in/out of the build and defines/undefines `MUX`, which
  in `main.c` registers or omits the `write/set/clear mux` commands and the
  `max14866_init()` call. The gain DAC lives in `max/dac.c` and is **always**
  built (it reuses the `max14866.pio` SPI-shifter program, always generated).
- To build just one: `cmake -B build2350 -DPICO_BOARD=pico2 -DMUX=OFF && cmake --build build2350`.
- **`-DDSP=ON`** (RP2350/`pico2` only; guarded with a FATAL_ERROR otherwise)
  enables the onboard-DSP feature set. As of P1 it only sets up the option +
  CMSIS-DSP (`cmsisdsp_p0rk` static lib); firmware sources land in later phases.

## Versioning & CI

- **`firmware/version.yaml`** (`version: "A.B.C"` + `changes: "..."`) is the
  single source of truth. CMake parses it, generates `version.h`
  (`FW_VERSION`, `FW_CHANGES`, `FW_BOARD`, `FW_CHIP`, `FW_RELEASE_URL`), and the
  `version` CLI command prints them.
- **Build metadata:** `FW_BOARD`/`FW_CHIP` come from `PICO_BOARD`;
  `FW_RELEASE_URL` is derived from the git remote + the `fw-v<version>` tag (it
  points at the release for the *clean* version even on a dirty build). The git
  hash is in a **separate** `version_git.h` regenerated on **every build** by
  `cmake/git_version.cmake` (`FW_GIT_HASH`, `-dirty` if `firmware/` has
  uncommitted changes).
- **Bump rule:** Claude bumps only the **patch (C)** on every change to
  `firmware/` files; the maintainer owns major/minor. A/B 0-99, C 0-999.
  (Python has its own identical scheme in `python/pic0rick/version.yaml`.)
- **`.github/workflows/firmware.yml`** builds all four variants on push/PR to
  `main`, uploads them as artifacts, and on **push to main** publishes a GitHub
  release tagged `fw-v<version>`. The release body lists **both** the firmware
  and python library versions + their `changes` (python has no separate release
  stream). It skips the release if that tag already exists; other branches never
  release.

## Gotchas

- **Wi-Fi secrets (resolved 2026-09-12):** a `firmware/.env` with plaintext
  `WIFI_SSID` / `WIFI_PASSWORD` used to sit here. It was **never committed**
  (untracked), the build never read it (no CYW43/Wi-Fi linked). It has been
  **deleted** and `.env` is now in both the root and `firmware/.gitignore`.
  If a `firmware/.env` reappears, it's a local-only secret — do not commit it.
- Two prebuilt UF2s (`rp2040.uf2`, `rp2350.uf2`) — pick by target board. These
  are the **mux** builds; nomux variants come from CI releases / `dist/`.
- There is a `version` command now (see Versioning above); the stdio build has
  **no** `status`/`help` handshake (those live in the DSP build's `main_dsp.c`).

## The two build flavours (one tree)

- **stdio / non-DSP** (`main.c`): text REPL over SDK `stdio_usb`; RP2040 or
  RP2350. `start acq` / `write dac` / `read` (raw 8000).
- **DSP** (`main_dsp.c`, `-DDSP`, RP2350 only): raw-TinyUSB command loop with the
  binary framed protocol + Hilbert envelope; adds `read_fft` (4096), `read_raw`
  (8000), `acq`/`stream`/`dsp`/`status`. Frame/status formats:
  `docs/dsp_output_formats.md`. Host side: `pic0rick.dsp` (see
  `python-host-tools.md`).

## Work log

- 2026-09-12: First-glance survey and this note created. Removed the untracked
  `firmware/.env` (Wi-Fi creds) and added `.env` to `firmware/.gitignore`. No
  source-code changes made to `firmware/`.
- 2026-09-13: Added `version` command + `version.yaml`/`version.h.in`; made the
  MAX14866 mux optional via `-DMUX` (split the DAC out to `max/dac.c` so it is
  always built); `build.sh` now builds 4 variants into `dist/`; added the
  `.github/workflows/firmware.yml` build+release workflow. Firmware v0.1.0.
  Verified all 4 variants build locally.
- 2026-09-13: v0.1.1 — `version` command now also prints board/chip, git build
  hash (`version_git.h`, regenerated every build via `cmake/git_version.cmake`,
  `-dirty` when firmware/ is dirty) and the derived release URL. CI release body
  now lists both firmware + python versions. Verified generated headers per
  variant.
- 2026-09-13: v0.1.2 — added `reboot-dfu` (reset_usb_boot → BOOTSEL; links
  `pico_bootrom`). **Flashed + tested on real RP2350A/Pico 2 W hardware**:
  `version` and the flash→run→`reboot-dfu`→BOOTSEL loop confirmed. See
  `hardware-testing.md`. (On branch `feature/unify-firmware-dsp`.)
- 2026-09-13: v0.1.3 — **P0 of the unify plan**: SDK 2.2.0→2.3.0 (CMakeLists +
  CI workflow ref). All 4 variants build; flashed rp2350 to hardware via the
  reboot-dfu loop and confirmed v0.1.3 runs. Toolchain kept at 14_2_Rel1 (the
  one installed; onboard_dsp nominally used 15_2 but 14_2 builds SDK 2.3.0 fine).
- 2026-09-13: v0.1.4 — **P1**: `-DDSP` option scaffolding (pico2-guarded) +
  CMSIS-DSP `cmsisdsp_p0rk` lib. No firmware sources yet; default builds
  unchanged. Verified guard + CMSIS-DSP fetch/build.
- 2026-09-13: v0.1.5 — **P2**: landed onboard-DSP modules in `firmware/dsp/`;
  built the USB-free set as the `p0rk_dsp` static lib (under `if(DSP)`). USB
  transport files copied but not compiled (P3). Default builds unchanged;
  `libp0rk_dsp.a` verified.
- 2026-09-13: v0.1.7 — **P4a**: two-length acquisition — `read_raw` (8000 raw)
  / `read_fft` (4096 envelope); per-job sample_count threaded through
  acquisition/pipeline/dsp. Verified frame sizes on hardware.
- 2026-09-13: v0.1.11 — **fix MUX/pulser PIO1 SM conflict (the real no-echo
  bug)**: `max14866_init` hardcoded pio1 sm0, clobbering the pulser drive SM
  (pio1 sm0). Now claims an unused SM. Echoes restored on MUX builds — verified
  vs the v0.1.1 baseline (`var[2000:3000]` 0.4 → ~52k at gain 300). **Watch out
  for hardcoded PIO SM indices** now that pulser+mux share PIO1.
- 2026-09-13: v0.1.10 — **pulser echo fix**: `hw/acquisition.c` `queue_pulse`
  now fires the bipolar pulse (both polarities back-to-back) **then** damps, as
  in v0.1.0. The shared `pulser.pio` path (P4b) had put PDAMP *between* the
  polarities, splitting the excitation (regression — user lost echoes). Transmit
  confirmed strong on hardware (~200 counts at sample ~31); echo-vs-target
  confirmation is up to the user's setup.
- 2026-09-13: v0.1.9 — **P6**: `build.sh` builds all 6 variants (adds the two
  rp2350 DSP builds) into `dist/`, sharing one CMSIS-DSP cache (`firmware/.deps`);
  CI caches it and builds/releases all 6.
- 2026-09-13: v0.1.8 — **P4b**: unified HW drivers. Moved the USB-free
  acquisition+pulser+spi1 DAC to `firmware/hw/` (shared by both builds); the
  stdio build's `start acq`/`write dac`/`read` now use them (raw 8000). Retired
  `adc/` (PIO pulser) and `max/dac.c` (PIO DAC). Verified on RP2350 hardware
  (stdio: write dac, 8000-sample start acq + read).
- 2026-09-13: v0.1.6 — **P3**: first runnable DSP build. `main_dsp.c` (raw
  TinyUSB command loop, selected under `if(DSP)`; stdio OFF) links `p0rk_dsp` +
  `usb_transport`/`usb_descriptors`; adds `version`/`reboot-dfu`/`write-set-clear
  mux`. Non-DSP `main.c` unchanged. **Tested on RP2350A hardware**:
  version/help/status + `acq raw` (8256-byte frame) all good. See
  `hardware-testing.md` (DSP CDC = raw TinyUSB, OK/ERR text + binary frames).

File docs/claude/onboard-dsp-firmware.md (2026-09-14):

# onboard_dsp firmware — RETIRED / merged into the mainline firmware

**As of 2026-09-13 (branch `feature/unify-firmware-dsp`), `experiments/onboard_dsp/`
no longer exists.** Its RP2350A DSP firmware was folded into the mainline
`firmware/` tree as an opt-in build, so there is one firmware source, not two.

## Where everything went

- **DSP firmware sources** → `firmware/dsp/` (`dsp.c`, `pipeline.c`,
  `protocol.c`, `usb_transport.c`, `usb_descriptors.c`, `tusb_config.h`) +
  `firmware/main_dsp.c` (the raw-TinyUSB command loop). Built with **`-DDSP=ON`**
  (RP2350/`pico2` only). See `firmware.md`.
- **Shared drivers** (used by both the stdio and DSP builds) → `firmware/hw/`
  (`acquisition.c/.pio`, `pulser.pio`, `dac.c` spi1, `u4rk.h`).
- **Host capture tool** → its reusable library is now `python/pic0rick/dsp.py`
  (frame reader + CRC + `parse_status` + `alaw_decode`), driven via
  `Pic0rick.status()/capture()/read_fft()/read_raw()`. See `python-host-tools.md`.
- **Output-format reference** (`understanding_figures.md`) →
  `docs/dsp_output_formats.md`.

## What changed vs the old onboard_dsp

- Two acquisition lengths: **`read_raw` = 8000** samples (raw), **`read_fft` =
  4096** (Hilbert envelope). The frame `sample_count` is now per-mode.
- Firmware version follows the repo `version.yaml` A.B.C scheme (no more the
  hard-coded `1.6` / `EXPECTED_FIRMWARE` handshake).
- Commands `version` and `reboot-dfu` added; `-DMUX` adds `write/set/clear mux`.

## Not carried over (see `docs/claude/TODO.md`)

- The old `test_guide.md` and `DSP_Tests.ipynb` (tightly coupled to the removed
  `tools/pic0rick_capture.py` CLI) were dropped. A fresh docs test-guide and a
  `python/` example notebook against `read_raw`/`read_fft` + `pic0rick.dsp` are
  TODO.

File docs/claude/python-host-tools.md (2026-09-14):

# python/ — host tools — working notes

Scope: repo-root **`python/`**. Host-side NDT (non-destructive testing) stack:
drive a pic0rick over serial, capture ADC traces, detect back-wall echoes,
estimate thickness, and store to HDF5. Full user-facing description lives in
`python/Readme.md` (created 2026-09-12).

## What targets what (important)

`python/` drives the unified `firmware/` in two ways:
- **stdio (non-DSP) build:** text commands `write dac` / `start acq` / `read`
  via `Pic0rick.dac()` / `pulse_adc_trigger()` / `read()`.
- **DSP (`-DDSP`) build:** binary framed protocol via `pic0rick/dsp.py` +
  `Pic0rick.status()/capture()/read_fft()/read_raw()` and the gain/pulse helpers
  `set_gain()/configure_pulse()/arm_pulser()/disarm_pulser()`.

As of 2026-09-14 `example_simple.ipynb` and `ndt_acquisition.from_probe()` use
the **DSP-build** path (`set_gain` + `configure_pulse` + `arm_pulser` +
`read_raw`).

## Files

- `pic0rick/__init__.py` — exposes `pic0rick.__version__` / `__changes__`, parsed
  from `pic0rick/version.yaml` (A.B.C, mirrors the firmware scheme). No pyserial
  import at package import time (kept lightweight).
- `pic0rick/version.yaml` — library version + `changes`. **Bump rule:** Claude
  bumps only the **patch (C)** on changes to `python/` files; maintainer owns
  major/minor. Independent of the firmware version.
- `pic0rick/device.py` — `Pic0rick` serial driver. `_find_port()` auto-detects
  the CDC port per-OS; methods `dac(N)`, `pulse_adc_trigger(pon,poff,damp)`,
  `read()`, and `write_mux(v)` / `set_mux()` / `clear_mux()` (match firmware,
  MUX builds). 115200 baud, `Fech=60e6`.
  - `version()` sends the firmware `version` command and parses the reply into a
    dict (`version`, `changes`, `board`, `chip`, `mux`, `mux_enabled`, `build`,
    `release`, `raw`); tolerates REPL echo/prompt lines.
  - **DSP-build gain/pulse helpers:** `set_gain(n)` (`dac write`),
    `configure_pulse(neg,damp,pos,order)`, `arm_pulser()`, `disarm_pulser()` —
    used by `example_simple.ipynb` and `ndt_acquisition.from_probe()`.
- `pic0rick/ndt_acquisition.py` — the real logic. `UltrasonicAcquisition`
  dataclass + `from_probe`, `detect_echoes`, `calibrate`, `amplitude`, `plot`,
  `info`, and HDF5 `save_h5`/`load_h5`. Hardware import is **lazy** (`get_probe`)
  so the module works offline for pure analysis.
- `example_acquisition.ipynb` — live-hardware workflow (gain sweep, calibrate
  best pon/poff, multi-thickness echo detection on a 1018-steel step block,
  5 MHz probe).
- `example_process.ipynb` — offline: `load_h5` a capture, pulse + autocorrelation
  analysis. No board needed.

## Notable details

- Signal decode in `from_probe` (2026-09-14): uses the DSP build — `set_gain`,
  `configure_pulse(negative_ns=poff, damp_ns=damp, positive_ns=pon, pos-first)`,
  `arm_pulser`, then `read_raw()` → `frame.samples()` (uint16 0..1023), mapped to
  `(x - 512) / 512` → normalized `[-1, 1]` float32 (8000 samples).
- HDF5 dedup key: `(gain, pon, poff, damp, target, piezo_id)`. A cache hit in
  `from_probe(h5_path=...)` skips the hardware unless `overwrite=True`.
- Notebooks read `../docs/data/calibration_block_5steps_1018steel.h5`.
- Deps: pyserial, numpy, scipy, h5py, matplotlib. No `requirements.txt` in
  `python/` yet.

## Work log

- 2026-09-12: Surveyed the folder and wrote `python/Readme.md` (points at both
  notebooks and both modules). No code changes.
- 2026-09-13: Added `write_mux`/`set_mux`/`clear_mux` to `Pic0rick` (firmware
  parity); added versioning (`__init__.py` + `version.yaml`, v0.1.0).
- 2026-09-13: v0.1.1 — added `Pic0rick.version()` parsing the firmware `version`
  report into a dict.
- 2026-09-14: v0.1.7 — example_dsp.ipynb reworked: pulser armed from start,
  A-law capture+decode plot, DSP self-test, pulser-order check, per-capture file
  saving (captures/<name>/); added dsp.SELFTEST_NAMES. Hardware-verified.
- 2026-09-14: v0.1.6 — surface Pico text replies: `dsp.describe_status()`,
  `status()['raw']`, `capture().last_reply`; DSP notebook prints replies + DSP µs
  stage times. Hardware-verified.
- 2026-09-13: v0.1.5 — added `python/example_dsp.ipynb` (step-by-step notebook;
  executed via nbconvert against the RP2350A) and fixed the DAC command in
  `example_dsp.py` (DSP build uses `dac write`, not `write dac`).
- 2026-09-13: v0.1.4 — added `python/example_dsp.py` (end-to-end DSP example) +
  `docs/dsp_test_guide.md`; hardware-tested. (v0.1.3 = docs-only after onboard_dsp
  retirement.)
- 2026-09-13: v0.1.2 — added `pic0rick/dsp.py` (DSP-build binary frame protocol:
  FrameReader+CRC, A-law decode, parse_status; length-agnostic for read_raw 8000
  / read_fft 4096) and `Pic0rick.status()/capture()/read_fft()/read_raw()`.
  Dropped the onboard tool's hard EXPECTED_FIRMWARE gate. Verified on hardware.

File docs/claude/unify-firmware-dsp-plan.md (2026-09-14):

# Plan: unify onboard_dsp into the mainline firmware (branch `feature/unify-firmware-dsp`)

**Goal:** one firmware source under `firmware/`. On **RP2350** a compile flag
pulls in the `experiments/onboard_dsp/` DSP features (Hilbert envelope + A-law,
dual-core, binary framed protocol), exposed as CLI commands. RP2040 keeps the
simple text build. When done, **retire `experiments/onboard_dsp/`**.

Decisions taken by the user (2026-09-13): fold DSP modules in and gate with a
flag (RP2350 only); DSP steps become new CLI commands; **SDK bump to 2.3.0 OK**;
retire onboard_dsp after merge.

---

## The pivotal constraint — USB model (confirm before Phase 3)

onboard_dsp bypasses SDK stdio (`pico_enable_stdio_usb 0`) and drives TinyUSB
directly (`usb_transport.c`/`usb_descriptors.c`/`tusb_config.h`) so text + binary
frames share one CDC. The mainline REPL uses SDK `stdio_usb`. **Only one USB
stack can own the CDC.**

- **Design A (recommended):** the DSP build uses onboard_dsp's raw-TinyUSB
  transport for *all* I/O; its `main.c` is already a line REPL that also emits
  frames. RP2040 (no DSP) keeps SDK stdio. Result: RP2350+DSP command set ≈
  onboard_dsp set + `version` (+ optional `mux`). Lowest risk — reuses the
  already-working transport.
- **Design B:** keep SDK stdio everywhere and push binary frames through stdout
  with `putchar_raw`. One command loop for both boards, but re-treads exactly
  what onboard_dsp deliberately avoided (stdio corrupting frames). Higher risk.

**Plan below assumes Design A.**

---

## Command reconciliation (overlaps with different semantics)

| Command | Mainline (RP2040/stdio) | onboard_dsp (RP2350/DSP) |
|---|---|---|
| `start acq` | `start acq <pon> <poff> <damp>` fires pulser+capture | `start acq` = legacy capture (no args) |
| `read` | dump 8000 hex | dump 4096 hex |
| DAC | `write dac <n>` (PIO) | `dac write <n>` (spi1) |
| MUX | `write/set/clear mux` (opt) | none |
| version | `version` | (uses `status` + version handshake) |

Approach: on the DSP build, adopt the onboard_dsp command names/semantics
(they're the richer set) and **add** `version`; keep `write/set/clear mux` when
`-DMUX`. Accept that `start acq`/`read` mean the 4096-sample DSP-build behaviour
on RP2350 vs the 8000-sample behaviour on RP2040 (documented, board-dependent).
Sample count differs by build (8000 vs 4096) — keep per-build constants.

## Hardware reconciliation
- **DAC:** unify on the onboard_dsp **spi1** driver (`u4rk_dac`, pins 13/14/15).
  Optionally switch the RP2040 build to it too (same pins/chip) to drop the PIO
  DAC — *needs a quick confirm it works on RP2040's spi1*. Default: DSP build
  uses spi1; RP2040 keeps PIO DAC unless we choose to unify.
- **Pulser:** onboard_dsp's 4-pin pulser (P+11/P-12/PDAMP16/OE17, `pulser.pio`)
  is a superset of the mainline 2-pin (GPIO11+16). **Needs hardware confirmation**
  of which pins the boards actually wire before merging the pulser. Until then,
  keep each build's own pulser.
- **MUX:** stays orthogonal (`-DMUX`); onboard_dsp leaves 18-21,28 free, so it
  can coexist on the DSP build.

---

## Phases (incremental; each ends buildable + committed with a commit log)

**P0 — SDK 2.3.0. ✅ DONE (fw v0.1.3, 2026-09-13).** Bumped
`firmware/CMakeLists.txt` sdk/picotool 2.2.0→2.3.0 (toolchain kept 14_2_Rel1 —
the installed one; onboard_dsp's 15_2 not required) and CI workflow pico-sdk ref
→2.3.0. All 4 variants build; rp2350 flashed + confirmed running on hardware.

**P1 — DSP option scaffolding. ✅ DONE (fw v0.1.4, 2026-09-13).** Added
`option(DSP ... OFF)`, the `pico2` guard (FATAL_ERROR on rp2040), and the
CMSIS-DSP `FetchContent` + `cmsisdsp_p0rk` static lib inside `if(DSP)`. No
firmware sources yet. Verified: default builds unchanged; guard rejects rp2040;
`-DDSP=ON -DPICO_BOARD=pico2` configures (fetches CMSIS-DSP v1.17.0) and builds
`libcmsisdsp_p0rk.a`. Note: the CMSIS-DSP shallow clone takes >2 min — CI time
cost to watch in P6.

**P2 — Land the modules. ✅ DONE (fw v0.1.5, 2026-09-13).** Copied all onboard
sources into `firmware/dsp/` (kept `u4rk_`/`U4RK_` names). Built the USB-free
compute/hardware set (`dsp`, `pipeline`, `protocol`, `acquisition`, spi1 `dac`)
as a **`p0rk_dsp` static library** under `if(DSP)` (with `acquisition.pio` +
`pulser.pio` headers, CMSIS-DSP link). `usb_transport.c`/`usb_descriptors.c`/
`tusb_config.h` are copied in-tree but **not compiled yet** — they belong with
the P3 raw-TinyUSB swap (they conflict with the stdio_usb REPL). Verified:
default builds unchanged; `libp0rk_dsp.a` builds under `-DDSP=ON -DPICO_BOARD=pico2`.

**P3 — Command loop. ✅ DONE (fw v0.1.6, 2026-09-13).** Added `main_dsp.c` (from
onboard_dsp `main.c`) selected in CMake under `if(DSP)`: SDK stdio OFF, links
`p0rk_dsp` + `usb_transport.c`/`usb_descriptors.c` + `tinyusb_device`, adds the
`version` + `reboot-dfu` commands and, under `-DMUX`, `write/set/clear mux`.
Non-DSP builds keep `main.c` (stdio) unchanged. Also fixed a missing
`U4RK_CMSIS_DSP_VERSION` compile define on the exe. **Verified on hardware
(RP2350A/Pico 2 W):** flashed the DSP+MUX build via reboot-dfu; `version`/`help`/
`status` return correctly over the raw-TinyUSB CDC and `acq raw` returns the
64-byte header + 8192-byte payload (8256 B). DSP+noMUX and all 4 default variants
also build.

**P4 — Reconcile hardware. ✅ DONE (fw v0.1.7 P4a + v0.1.8 P4b, 2026-09-13).**
Decisions (2026-09-13):
- **DAC:** unify both builds on the spi1 `u4rk_dac` (bit-identical to the PIO DAC:
  `0x3000|(value<<2)`, same pins 13/14/15). PIO DAC (`max/dac.c`) retired.
- **Pulser pins already match** (11/12/16/17) across both firmwares.
- **Two-length acquisition (user design):** sample count is **mode-dependent**,
  not build-dependent, because the 4096 cap is only the CMSIS `arm_rfft_fast_f32`
  limit (max power-of-two = 4096), not memory/ADC.
  - `read_raw` → **8000** samples, raw ADC, no FFT (both builds).
  - `read_fft` → **4096** samples, envelope/FFT (DSP build only).
  Frame header already carries `sample_count`; max payload unchanged (4096 floats
  = 16384 B ≥ 8000×u16 = 16000 B). Threaded a per-job `sample_count` through
  acquisition/pipeline/dsp; raw buffers sized to 8000.
- **stdio/RP2040 build:** uses the shared acquisition+pulser+dac in raw-8000 mode
  (one implementation).

**P5 — Host + version. ✅ DONE (python v0.1.2, 2026-09-13).** Added
`python/pic0rick/dsp.py` (binary frame reader + CRC, A-law decode, `parse_status`),
made **length-agnostic** (payload size derived from the header `sample_count`, so
read_raw 8000 / read_fft 4096 both parse). Added `Pic0rick.status()` /
`capture()` / `read_fft()` / `read_raw()`. Dropped the hard `EXPECTED_FIRMWARE
== "1.6"` gate — the host now just parses whatever `firmware=A.B.C` the board
reports. Verified on hardware: status + read_fft (4096 f32) + read_raw (8000 u16).

**P6 — Build matrix + CI. ✅ DONE (fw v0.1.9, 2026-09-13).** `build.sh` builds
all 6 (rp2040 mux/nomux, rp2350 mux/nomux, rp2350 mux/nomux +DSP) into `dist/`,
sharing one CMSIS-DSP clone (`firmware/.deps`, gitignored, via
`FETCHCONTENT_BASE_DIR`). CI caches `firmware/.deps` and its artifact/release
globs (`dist/*.uf2`) pick up all 6 automatically. Firmware patch bump.

**P7 — Retire onboard_dsp. ✅ DONE (py v0.1.3, 2026-09-13).** Removed
`experiments/` entirely. Kept the format spec (`understanding_figures.md` →
`docs/dsp_output_formats.md`). Dropped `test_guide.md` + `DSP_Tests.ipynb` +
`tools/pic0rick_capture.py` (superseded by `pic0rick.dsp`; rewrite logged in
TODO). Updated all references (CLAUDE.md, docs/claude notes, python/Readme,
dsp.py) and rewrote `onboard-dsp-firmware.md` as a pointer. `check-links`: no
genuine local breaks.

**P8 — Docs + versions. ✅ DONE (2026-09-13).** Root `README.md` updated
(building section, `-DDSP`/`-DMUX`, `version`/`reboot-dfu` commands, a DSP-build
section pointing at `pic0rick.dsp` + `docs/dsp_output_formats.md`). `firmware.md`,
`python-host-tools.md`, `CLAUDE.md`, DONE/commit logs and memory kept current
throughout P0–P7.

---

## ✅ Unification complete (2026-09-13)

All phases P0–P8 done on `feature/unify-firmware-dsp` (pushed). One firmware
source tree (`firmware/`) with `-DMUX` and `-DDSP` build options; shared drivers
in `firmware/hw/`; DSP feature set in `firmware/dsp/`; one host stack in
`python/` (`pic0rick.dsp`); `experiments/onboard_dsp/` removed. Firmware at
v0.1.9, python at v0.1.3. Verified on RP2350A hardware at each phase.

**Not merged to main** — awaiting the maintainer's PR/merge (merging cuts a
GitHub release fw-v0.1.9 via CI). Open follow-ups in `TODO.md`: DSP test
guide + example notebook; optional pulser scope validation; optional capture CLI.

---

## Decisions (locked 2026-09-13)
1. **USB model: Design A** — DSP build adopts onboard_dsp's raw-TinyUSB transport
   + CLI loop; RP2040 keeps SDK stdio. ✅
2. **DAC: spi1 on the DSP build, PIO DAC unchanged on RP2040.** ✅ (no RP2040
   behaviour change; PIO DAC + `max14866.pio` shifter stay for the non-DSP path.)

## Still needed (later phases, not blocking P0–P3)
3. **Pulser pin map:** which pins the real RP2040 vs RP2350 boards wire — blocks
   the P4 pulser merge. Until then each build keeps its own pulser.
4. **Version handshake:** intend to replace onboard_dsp's
   `EXPECTED_FIRMWARE == "1.6"` gate with the `version.yaml` A.B.C scheme in P5 —
   confirm when we get there.

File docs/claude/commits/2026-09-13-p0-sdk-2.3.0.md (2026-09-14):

# 2026-09-13 — P0: bump Pico SDK to 2.3.0

Firmware **v0.1.3**. Branch `feature/unify-firmware-dsp`. First phase of the
onboard-DSP unification plan.

## What
- `firmware/CMakeLists.txt`: `sdkVersion` and `picotoolVersion` 2.2.0 → 2.3.0.
  Toolchain kept at `14_2_Rel1` (the only one installed here; SDK 2.3.0 builds
  fine with it — onboard_dsp nominally set 15_2_Rel1 but it isn't required).
- `.github/workflows/firmware.yml`: pico-sdk checkout `ref` 2.2.0 → 2.3.0.

## Why
The onboard-DSP merge needs SDK 2.3.0 (matches onboard_dsp; CMSIS-DSP setup).
Doing the bump first, in isolation, keeps the risky change separate.

## Verification
- All 4 variants build against `~/.pico-sdk/sdk/2.3.0` (confirmed via
  CMakeCache PICO_SDK_PATH). `version.h` = 0.1.3.
- Hardware: used the running v0.1.2 `reboot-dfu` to enter BOOTSEL, flashed
  `pic0rick-v0.1.3-rp2350-mux.uf2`, and confirmed over serial the board runs
  v0.1.3 (`board: pico2 (RP2350)`, SDK-2.3.0 build). Whole loop needed no
  button press.

## Notes
- SDK 2.3.0 emits `find_compiler` CMake *warnings* while probing toolchain
  triples before settling on `arm-none-eabi-gcc` — harmless.

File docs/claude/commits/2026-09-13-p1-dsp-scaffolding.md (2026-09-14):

# 2026-09-13 — P1: -DDSP option scaffolding + CMSIS-DSP

Firmware **v0.1.4**. Branch `feature/unify-firmware-dsp`.

## What
In `firmware/CMakeLists.txt`:
- `option(DSP "..." OFF)`.
- Guard: `if(DSP AND NOT PICO_BOARD STREQUAL "pico2") -> FATAL_ERROR` (the DSP
  pipeline needs the RP2350 FPU).
- Inside `if(DSP)`: CMSIS-DSP v1.17.0 `FetchContent` + the `cmsisdsp_p0rk` static
  lib (the float32 transform subset only), copied from the onboard_dsp CMake.

No firmware sources added; the executable does not yet use DSP. Default builds
are byte-unchanged apart from the version string.

## Why
First build-system step of the unification: make the DSP toolchain available and
board-gated before landing the modules (P2).

## Verification
- Default (DSP off): all 4 variants build at v0.1.4; feature reports "disabled".
- Guard: `-DDSP=ON -DPICO_BOARD=pico` → FATAL_ERROR as intended.
- `-DDSP=ON -DPICO_BOARD=pico2`: configure exit 0, CMSIS-DSP fetched, and
  `cmake --build --target cmsisdsp_p0rk` produced `libcmsisdsp_p0rk.a` (736 KB).
  (Done in a scratch build dir, not the repo.)

## Finding (for P6/CI)
The CMSIS-DSP shallow clone takes >2 min locally; CI will pay this on DSP builds.
Consider caching `_deps` or a submodule/mirror when wiring DSP into CI.

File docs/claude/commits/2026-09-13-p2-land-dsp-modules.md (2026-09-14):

# 2026-09-13 — P2: land onboard-DSP modules as p0rk_dsp static lib

Firmware **v0.1.5**. Branch `feature/unify-firmware-dsp`.

## What
- Copied all onboard sources into **`firmware/dsp/`** (kept `u4rk_`/`U4RK_`
  names): `dsp.[ch]`, `pipeline.[ch]`, `protocol.[ch]`, `acquisition.[ch]` +
  `acquisition.pio`, `pulser.pio`, spi1 `dac.[ch]`, `u4rk.h`, plus
  `usb_transport.[ch]`, `usb_descriptors.c`, `tusb_config.h`.
- Added a **`p0rk_dsp` static library** (CMake, inside `if(DSP)`) compiling the
  USB-free compute/hardware set: `dsp/pipeline/protocol/acquisition/dac`. Wires
  the two PIO headers, CMSIS-DSP link (`cmsisdsp_p0rk`), and the pico libs
  (`pico_multicore`/`pico_util`/`hardware_spi`/…).

## Why (scope split)
`usb_transport.c`/`usb_descriptors.c` provide TinyUSB device callbacks that
conflict with the SDK `stdio_usb` REPL currently in `main.c`. They can't be
compiled into a build alongside stdio_usb, so they're deferred to **P3**, where
the DSP build switches to the raw-TinyUSB command loop. P2 keeps everything
buildable and verifies the compute modules compile in-tree.

## Verification
- Default (DSP off): all 4 variants build at v0.1.5 (unchanged).
- `-DDSP=ON -DPICO_BOARD=pico2`: `cmake --build --target p0rk_dsp` →
  `libp0rk_dsp.a` (1.87 MB), no errors/warnings. (Scratch build dir.)

## Notes
- The originals under `experiments/onboard_dsp/firmware/pic0rick/` are unchanged;
  they're removed in P7.
- `p0rk_dsp` is not yet linked into the `adc-pulse` executable (P3).

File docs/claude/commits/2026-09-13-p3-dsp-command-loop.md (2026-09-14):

# 2026-09-13 — P3: runnable DSP build (raw-TinyUSB command loop)

Firmware **v0.1.6**. Branch `feature/unify-firmware-dsp`. First *runnable* DSP
firmware.

## What
- Added `firmware/main_dsp.c` (adapted from onboard_dsp `main.c`): the raw-TinyUSB
  line command loop that also emits binary frames. Extras vs onboard:
  - `version` command → the standard version block (FW_VERSION/board/chip/mux/
    build/release), so the existing `Pic0rick.version()` parser works.
  - `reboot-dfu` command → `reset_usb_boot(0,0)`.
  - Under `-DMUX`: `write mux <hex>`, `set mux`, `clear mux` (+ `max14866_init()`
    at boot); listed in `help`.
- CMake: split the executable into `if(DSP)` (raw TinyUSB) / `else` (stdio REPL):
  - DSP: `pico_enable_stdio_usb(0)`, sources `main_dsp.c` +
    `dsp/usb_transport.c` + `dsp/usb_descriptors.c`, include `firmware/dsp`,
    defines `DSP=1` + `U4RK_CMSIS_DSP_VERSION="1.17.0"`, links `tinyusb_device`
    + `p0rk_dsp`; MUX adds `max/max14866.c` + `max14866.pio`. The PIO DAC
    (`max/dac.c`) and mainline PIO ADC (`adc/adc.c`) are NOT built (spi1 DAC +
    acquisition come from `p0rk_dsp`).
  - non-DSP: unchanged stdio path (`main.c`, `adc/adc.c`, `max/dac.c`, …).

## Why
Design A (locked earlier): the DSP build owns the CDC via raw TinyUSB so text +
binary frames coexist; RP2040/non-DSP keeps SDK stdio.

## Verification (RP2350A / Pico 2 W hardware)
Flashed the DSP+MUX build via the reboot-dfu loop:
- `version` → v0.1.6, `board: pico2 (RP2350)`, `mux: enabled`.
- `help` → full command list incl. version/reboot-dfu/mux.
- `status` → `package=RP2350A samples=4096 dsp_backend=f32-rfft-hilbert
  cmsis=1.17.0 …`.
- `acq raw` → `OK capture started type=raw` + 8256 B (64 hdr + 8192 payload).
Also: DSP+noMUX builds; all 4 default (non-DSP) variants build unchanged.

## Fix
Added the missing `U4RK_CMSIS_DSP_VERSION` compile define (onboard set it in
CMake; `send_status()` uses it).

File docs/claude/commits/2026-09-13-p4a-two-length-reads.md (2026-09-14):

# 2026-09-13 — P4a: two-length acquisition (read_raw 8000 / read_fft 4096)

Firmware **v0.1.7**. Branch `feature/unify-firmware-dsp`.

## What
Made the capture length **per-mode** instead of a single fixed 4096:
- `read_raw` → 8000-sample raw ADC (no FFT).
- `read_fft` → 4096-sample Hilbert envelope (CMSIS `arm_rfft_fast` max).
- Threaded a per-job `sample_count` through `u4rk.h` (job struct + new
  `U4RK_RAW_SAMPLE_COUNT=8000`, `U4RK_MAX_SAMPLE_COUNT`), `acquisition.c`
  (`u4rk_capture_start(dest, count)`), `dsp.c` (`u4rk_dsp_extract(.., count)`),
  and `pipeline.c` (raw buffers sized to max; header `sample_count`, payload
  size and latest-raw copy all length-aware; `copy_latest_raw` now returns the
  count). `main_dsp.c` picks 8000 for raw / 4096 for envelope|alaw, keeps
  selftest at 4096, and `legacy_read` dumps the stored count.

## Why (design, from the user)
The 4096 cap is only the CMSIS `arm_rfft_fast_f32` limit (max power-of-two),
not a memory/ADC limit — so raw can stay 8000 while the FFT path uses 4096, on
one firmware. Max payload is unchanged (4096 floats = 16384 B ≥ 8000 u16 =
16000 B); the frame header's `sample_count` makes frames self-describing.

## Verified on hardware (RP2350A / Pico 2 W, DSP+MUX)
Flashed via reboot-dfu:
- `read_raw` → `OK … type=raw samples=8000`; frame 16064 B = 64 hdr + 16000
  (8000×u16); header sample_count=8000.
- `read_fft` → `OK … type=envelope samples=4096`; frame 16448 B = 64 + 16384
  (4096×float); header sample_count=4096.
All 4 default (non-DSP) variants build unchanged.

## Next (P4b)
Unify the stdio/RP2040 build onto the shared acquisition+pulser+spi1 DAC (raw
8000). Requires moving the USB-free modules out of firmware/dsp/ (which holds
tusb_config.h) into a shared dir so the stdio build can include them without
clashing with SDK stdio's TinyUSB.

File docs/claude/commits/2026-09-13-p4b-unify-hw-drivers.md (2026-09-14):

# 2026-09-13 — P4b: unify hardware drivers (stdio + DSP share firmware/hw)

Firmware **v0.1.8**. Branch `feature/unify-firmware-dsp`.

## What
- Moved the USB-free drivers out of `firmware/dsp/` into a shared
  **`firmware/hw/`**: `acquisition.[ch]`/`acquisition.pio`, `pulser.pio`,
  `dac.[ch]` (spi1), `u4rk.h`. (They can't live next to `tusb_config.h`, which
  the stdio build's SDK TinyUSB would wrongly pick up.)
- Rewrote the stdio `main.c` to use the shared drivers: `write dac` →
  `u4rk_dac_write`; `start acq [pon] [poff] [damp]` → configure+arm the shared
  pulser and capture 8000 samples (polled, single-threaded); `read` → dump 8000.
- **Retired** `firmware/adc/` (PIO pulser/ADC) and `firmware/max/dac.c` (PIO DAC).
- CMake: both branches compile `hw/acquisition.c` + `hw/dac.c`; `p0rk_dsp` sources
  them from `hw/`; stdio build links `hardware_spi`.

## Why
User: "backport the onboard pulser to stdio too" for one shared implementation.
Both builds now drive the same acquisition + pulser + spi1 DAC on the same pins
(11/12/16/17 pulser, 13/14/15 DAC).

## Verified on hardware (RP2350A / Pico 2 W, stdio rp2350-mux build)
Flashed via reboot-dfu:
- `version` → v0.1.8.
- `write dac 500` → `dac=500`.
- `start acq 200 200 2000` → "Acquisition of 8000 samples started / ended"
  (DMA completed, no timeout).
- `read` → ~8000 hex ADC samples, End-of-ACQ marker, values sane (mean ~410).
All 4 default variants + the DSP build compile.

## Notes / caveats
- The stdio `start acq` now drives the u4rk pulse sequence (positive-first,
  OE-gated) rather than the old PIO pulse1/pulse2 waveform. Mapping:
  positive_ns=pon, negative_ns=poff, damp_ns=damp. Validated at command/data
  level only (no scope, per the connected setup).
- `firmware/adc/` is now empty (untracked dir remains; git tracks no files there).

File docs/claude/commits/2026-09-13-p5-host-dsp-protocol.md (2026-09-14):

# 2026-09-13 — P5: DSP-build host protocol in python

Python library **v0.1.2**. Branch `feature/unify-firmware-dsp`.

## What
- Added `python/pic0rick/dsp.py`, ported from
  `experiments/onboard_dsp/tools/pic0rick_capture.py`:
  - `FrameReader` (skips text/noise, parses the 64-byte header, validates CRC32),
    `Frame`/`FrameHeader`, `alaw_decode`, `parse_status`.
  - **Length-agnostic:** payload size is derived from the header `sample_count`
    (`expected_payload_bytes`), so `read_raw` (8000) and `read_fft` (4096) both
    parse on one firmware.
- Added `Pic0rick` methods (DSP firmware): `status()` (parsed dict),
  `capture(payload)`, `read_fft()`, `read_raw()`.

## Version handshake
Dropped the onboard tool's hard `EXPECTED_FIRMWARE == "1.6"` reject. The host now
just parses `firmware=A.B.C` from the status line (matches our version.yaml
scheme); callers can compare if they wish.

## Verified on hardware (RP2350A, DSP build)
Driven via the library:
- `status()` → firmware 0.1.8, dsp_backend f32-rfft-hilbert, samples 4096.
- `read_fft()` → envelope frame, sample_count 4096, payload 16384 B, CRC OK,
  float32[4096], peak 193.
- `read_raw()` → raw frame, sample_count 8000, uint16[8000], sane values.
Offline: parse_status + expected_payload_bytes unit-checked.

## Note
The CLI/app parts of the old tool (argparse `run`, `save_frames`,
`validate_selftest`) were not ported — only the reusable library. They can be
re-added later if a standalone capture CLI is wanted. The old tool stays until
P7 removes `experiments/onboard_dsp/`.

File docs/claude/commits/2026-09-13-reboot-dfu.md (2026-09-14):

# 2026-09-13 — reboot-dfu command + first hardware test

Firmware **v0.1.2**. Branch `feature/unify-firmware-dsp`.

## What
- Added `reboot-dfu` CLI command to `firmware/main.c`: prints a notice, flushes,
  then `reset_usb_boot(0, 0)` (`pico/bootrom.h`) to reboot into the USB
  bootloader (BOOTSEL / UF2 mass storage, aka "DFU").
- Linked `pico_bootrom` in `firmware/CMakeLists.txt`.

## Why
A physical RP2350A/Pico 2 W dev board is connected for testing. `reboot-dfu`
lets us re-enter the bootloader from the CLI so successive UF2 builds can be
flashed without pressing BOOTSEL — closing the flash/test iterate loop.

## Verified on hardware (RP2350A / Pico 2 W, pico2 build)
- Built all 4 variants; flashed `pic0rick-v0.1.2-rp2350-mux.uf2` by copying to
  the BOOTSEL mass storage at `/media/kelu/RP2350`.
- Device booted to CDC `/dev/ttyACM0`; `version` reported
  `board: pico2 (RP2350)`, `mux: enabled`, `release: .../fw-v0.1.2`.
- `reboot-dfu` dropped the CDC and re-entered BOOTSEL (`2e8a:000f`) in ~2 s;
  reflashing from the re-mounted MSD restored the running firmware.

## Notes / new docs
- Full flashing + serial + DFU-loop recipe recorded in
  `docs/claude/hardware-testing.md` (and memory).
- Build hash showed `-dirty` because the uf2 was built before committing.
- We build/flash `pico2` (not `pico2_w`) since wifi is unused; switch to
  `pico2_w` if CYW43 is ever needed.

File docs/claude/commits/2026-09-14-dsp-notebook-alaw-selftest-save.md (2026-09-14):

# 2026-09-14 — example_dsp.ipynb: arm-from-start, A-law, self-test, file saving

Python library **v0.1.7**. Branch `feature/unify-firmware-dsp`.

## What (per user request)
Reworked `python/example_dsp.ipynb` to combine the user's early-arm tweak with
the richer steps from the retired onboard_dsp `DSP_Tests.ipynb`:
- **Pulser armed from the start** (gain + `dsp scale` + `pulse config` + `pulser
  arm` before any capture), disarmed at the end.
- **A-law** section: `acq alaw` → `dsp.alaw_decode(bytes, reference)` overlaid on
  the Hilbert envelope (the user wanted the A-law signal shown too).
- **DSP self-test**: streams the 21 vectors, read via `FrameReader`, summarized
  by case name (`dsp.SELFTEST_NAMES`) + envelope peak.
- **Pulser-order** check (pos-first vs neg-first transmit region).
- **Per-capture file saving** (`grab()` helper): `captures/<name>/<payload>.npy`
  + `header.json` + `status.txt`; a final cell lists the saved tree.
- Every Pico text reply + per-stage DSP µs times shown throughout.
- Added `dsp.SELFTEST_NAMES` to `pic0rick/dsp.py`.
- `.gitignore`: `captures/`, `python/raw.npy`, `python/envelope.npy`.

## Verified on hardware (RP2350A, DSP v0.1.11, mux, pulser armed)
Executed via `jupyter nbconvert --execute` (exit 0):
- raw (min/mean/max 1/567/1023 — saturating with the pulser), envelope
  (peak 984.8), A-law (uint8 1..255, ref 512) all captured + saved.
- self-test: 21 frames, cases zero/dc/sinusoid/am/two-bursts/impulse/clipping
  with expected increasing peaks (…impulse 510.9, clipping 1276.7).
- per-stage DSP µs shown (e.g. forward_fft ~4.4 ms, dsp_us ~10.7 ms).
- `captures/{raw,envelope,alaw}/` files written; cleaned after the test.

## Note
Full CLI-style `validate_selftest`/`run` from the old tool were not re-added; the
notebook reads + summarizes the self-test frames instead. Can port strict
numeric validation later if wanted.

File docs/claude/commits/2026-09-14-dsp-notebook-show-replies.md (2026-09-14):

# 2026-09-14 — DSP notebook shows Pico text replies + us times

Python library **v0.1.6**. Branch `feature/unify-firmware-dsp`.

## What
- `pic0rick/dsp.py`: added `describe_status()` — a readable multi-line summary of
  a status line/dict, including the per-stage DSP microsecond times.
- `pic0rick/device.py`: `status()` now includes the raw Pico line under `"raw"`;
  `capture()` records the leading `OK capture started ...` control line as
  `self.last_reply`.
- `python/example_dsp.ipynb`: each step now prints the Pico's text replies —
  `version` (verbatim), `status` (raw line + `describe_status` breakdown),
  `dac write` reply, the `OK capture started ...` line per capture, the frame
  header params, and after `read_fft` the DSP stage/us times; pulser commands
  echo their `OK ...` replies.

## Why
User wanted to see the device's text answers (parameters + µs times) in the
notebook.

## Verified on hardware (RP2350A, DSP v0.1.11, mux)
Executed via `jupyter nbconvert --execute`, exit 0. Sample output:
- status stage times after a read_fft: preprocess 544, forward_fft 4539, mask
  159, inverse_fft 4528, magnitude 1066 us; dsp_us 10841 (over-budget).
- `OK dac=300`, `OK capture started type=raw samples=8000`, etc. all shown.
- Pulsed envelope peak 1164 vs idle 94.5 (echoes present on the mux build).

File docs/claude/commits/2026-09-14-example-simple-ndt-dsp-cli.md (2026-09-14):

# 2026-09-14 — example_simple + ndt_acquisition on the DSP CLI

Python library **v0.1.8**. Branch `feature/unify-firmware-dsp`.

## What
- Added DSP-build helpers to `Pic0rick`: `set_gain(n)` (`dac write`),
  `configure_pulse(neg,damp,pos,order)`, `arm_pulser()`, `disarm_pulser()`.
- Rewrote `python/example_simple.ipynb` to the new CLI: version → `set_gain` →
  `configure_pulse` + `arm_pulser` → `read_raw()` (binary frame) → plot →
  `disarm_pulser`.
- Migrated `ndt_acquisition.from_probe()` to the same path: `set_gain` +
  `configure_pulse(negative_ns=poff, damp_ns=damp, positive_ns=pon, pos-first)` +
  `arm_pulser` + `read_raw()`; `signal = (frame.samples() - 512) / 512`
  (replaces the old stdio `dac`/`pulse_adc_trigger`/`read` hex-text path).

## Why
User: rewrite example_simple with the new CLI commands, and make
ndt_acquisition match. Both now target the DSP (`-DDSP`) build the board runs.

## Verified on hardware (RP2350A, DSP v0.1.11, mux)
- `ndt.from_probe(Fech=60e6, pon=200, poff=200, damp=2000, gain=50)` → float32
  (8000,), normalized [-1,1], echoes present (`var[2000:3000]` 0.014 vs
  `[6000:7000]` 0.0000).
- `example_simple.ipynb` executed via nbconvert (exit 0): version v0.1.11,
  `OK pulser armed`, `OK capture started type=raw samples=8000`, plot rendered.

## Note
The stdio methods (`dac`/`pulse_adc_trigger`/`read`) remain for the non-DSP
build; `from_probe` and example_simple now use the DSP build.

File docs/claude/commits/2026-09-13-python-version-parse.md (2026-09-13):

# 2026-09-13 — Python: parse the firmware `version` command

Python library **v0.1.1**.

## What
- Added `Pic0rick.version()` to `python/pic0rick/device.py`: sends `version\n`
  to the firmware and parses the multi-line reply into a dict
  (`version`, `changes`, `board`, `chip`, `mux`, `mux_enabled`, `build`,
  `release`, plus `raw`). Missing lines are simply absent from the dict.
- Added `import re`.

## Why
The firmware `version` command (fw v0.1.1) reports board/chip, mux, git hash and
release URL; the host library had no way to read it back. Lets a host script
confirm which firmware/board/mux build a connected device is running.

## Notes
- Tolerant parsing: matches on line prefixes (`changes:`/`board:`/`mux:`/
  `build:`/`release:`) and a `firmware vX.Y.Z` regex, so REPL echo (`run> `) and
  the prompt are ignored.
- `mux_enabled` is a convenience bool derived from the `mux:` line.

## Verification
Ran the parse logic against a simulated response (with `run> ` echo + prompt);
produced the expected dict. `device.py` passes `ast.parse`.
Not exercised against live hardware.

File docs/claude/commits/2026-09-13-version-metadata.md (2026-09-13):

# 2026-09-13 — version command build metadata + dual-version release notes

Firmware **v0.1.1**.

## What
- `version` CLI command now prints, in addition to version + changes:
  - `board` / `chip` — from `PICO_BOARD` (`pico`→RP2040, `pico2`→RP2350).
  - `mux` — enabled/disabled (already had this).
  - `build` — git short hash, `-dirty` when `firmware/` has uncommitted changes.
  - `release` — GitHub release URL derived from the git remote + `fw-v<version>`.
- Version headers:
  - `version.h.in` gains `FW_BOARD`, `FW_CHIP`, `FW_RELEASE_URL` (configure-time).
  - New `version_git.h.in` + `cmake/git_version.cmake` regenerate `FW_GIT_HASH`
    on **every build** (custom target `gen_git_version`, a dependency of
    `adc-pulse`, plus a configure-time run so the header always exists).
- CI (`.github/workflows/firmware.yml`): release body now composed from BOTH
  `firmware/version.yaml` and `python/pic0rick/version.yaml` (version + changes),
  written to `release_body.md` and passed via `body_path`. No separate python
  release stream (per maintainer decision).

## Design decisions (from the discussion)
- Git hash captured at build time (not just configure) so incremental local
  builds stay honest; dirty check scoped to `firmware/` so unrelated repo changes
  (e.g. hardware/, .vscode/) don't flag it.
- On a dirty build the `release` URL still shows the clean `fw-v<version>` link;
  the `-dirty` in the `build` line is the signal that the tree isn't that exact
  tag. (Maintainer chose this over marking the URL unpublished.)
- Python version is a snapshot inside the firmware release body; python-only
  changes still don't cut a release (intended — library is used from source).

## Verification
Built all 4 variants locally. Confirmed generated headers:
- rp2350-mux: BOARD=pico2, CHIP=RP2350, RELEASE_URL=.../fw-v0.1.1,
  GIT_HASH=b0d9435-dirty.
- rp2040-nomux: BOARD=pico, CHIP=RP2040, no `MUX=1` define.

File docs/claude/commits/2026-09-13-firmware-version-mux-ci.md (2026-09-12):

# 2026-09-13 — Firmware version command, optional MUX (-DMUX), CI release

Firmware **v0.1.0** (first versioned release).

## What
1. **Versioning** — added `firmware/version.yaml` (`version: "A.B.C"` +
   `changes`) as the single source of truth. `CMakeLists.txt` parses it and
   `configure_file`s `version.h.in` → generated `version.h` (`FW_VERSION`,
   `FW_CHANGES`). New `version` CLI command prints version + changes + mux state.
2. **Optional MUX** — new CMake `option(MUX ... ON)`. When `-DMUX=OFF`,
   `max/max14866.c` is excluded and `MUX` is undefined, so `main.c` omits the
   `write/set/clear mux` commands and `max14866_init()`.
3. **DAC split** — moved the MCP4812 gain DAC out of `max/max14866.c` into new
   `max/dac.c` + `max/dac.h`. The DAC is always built (gain control is not part
   of the mux module). Both reuse the `max14866.pio` SPI-shifter program, which
   is always generated.
4. **build.sh** — now builds 4 variants (rp2040/rp2350 × mux/nomux) into
   `firmware/dist/` and refreshes the historical `rp2040.uf2` / `rp2350.uf2`
   (mux builds).
5. **CI** — `.github/workflows/firmware.yml`: build all 4 on push/PR to main,
   upload artifacts; on **push to main** publish a release `fw-v<version>` with
   the 4 uf2 attached and `changes` as the body. Skips if the tag exists; never
   releases on other branches.

## Why
User wants: a version command sourced from a yaml (with a changelog line usable
by the release workflow); the MAX14866 plug-in board selectable at compile time
producing separate artifacts; and automatic releases from main.

## Verification
Built all 4 variants locally (pico-sdk 2.2.0, arm-none-eabi-gcc). Confirmed:
- `version.h` embeds `0.1.0` + changes text.
- mux build compiles `max14866.c.o` + `dac.c.o`; nomux build compiles only
  `dac.c.o` (max14866 correctly excluded).

## Notes / caveats
- Release is skipped when `fw-v<version>` already exists (can't reuse a tag), so
  a main push that doesn't bump the firmware version produces artifacts but no
  new release. This is intentional (see TODO if the maintainer wants per-commit
  releases regardless).
- CI pins pico-sdk to 2.2.0 (matches CMakeLists sdkVersion).

## Rule added
Firmware patch (C) is bumped by Claude on every change to `firmware/` files;
maintainer owns major/minor. Recorded in `docs/claude/README.md` and memory.

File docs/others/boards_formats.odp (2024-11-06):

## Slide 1

Fast ADC pHAT

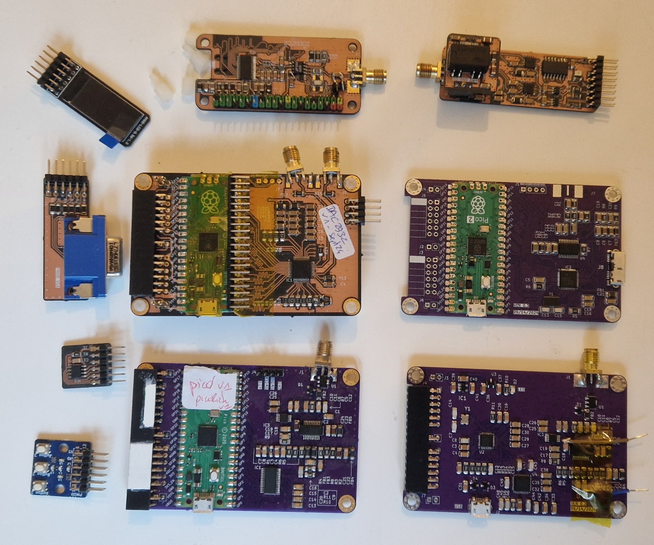
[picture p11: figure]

HV Board (+-24V)

OLED PMOD

Bipolar pulser PMOD

40Msps dual DAC

DAC2932 DAC board

FT600Q board
100Msps ADC

+ USB3 bridge

6bits VGA PMOD

PSRAM PMOD

User Interface (icebreaker) PMOD (buttons/LEDs)

pic0rick

10bits 80Msps ADC

+ AD8331 amp

MSI SDR board
USB2-based

Mirics MSI2500 + MSI001

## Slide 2

Probe accoustic window

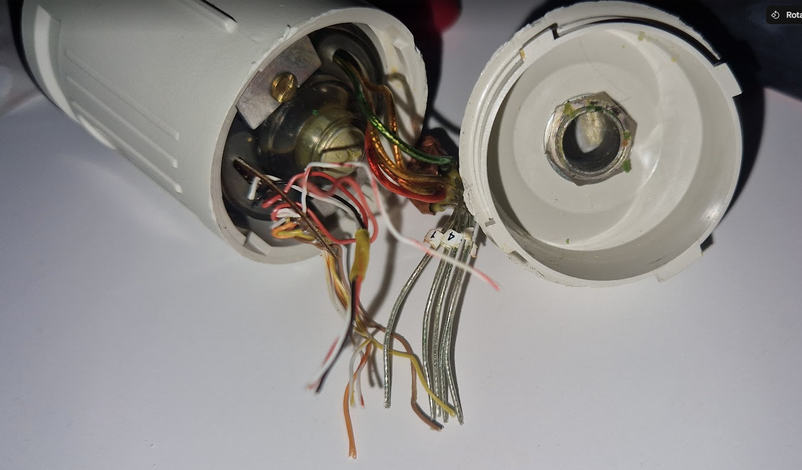
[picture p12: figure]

Probe casing

Motor control (simple wires)

5 coax for each part of the annular array

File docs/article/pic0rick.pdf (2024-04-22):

## A RP2040-BASED ULTRASOUND PULSE-ECHO ACQUISITION DEVICE

A MODULAR OPEN-SOURCE DEVICE FOR ULTRASOUND RESEARCH

Luc Jonveaux∗
Tinkerer, Milly le Meugon, France contact@un0rick.cc

April 13, 2024

ABSTRACT

After a couple of iterations for single-element ultrasound pulse-echo devices, the pic0rick choses simplicity to reach a modular design, allowing for bipolar pulser, fast acquisition and relatively simple, barebone design. No FPGA, no BGA, plain old raspberry pico.

Keywords arduino · open-source · ultrasound · single element · pulse echo · hardware · rp2040 · lowtech

This PDF is also a ZIP that contains the sources to the hardware and some data too, don’t hesitate to have a look. Just rename the file from .PDF to .ZIP and you’re ready to go .

### 1 Overview

The pic0rick is a very central board for an ultrasound pulse-echo system. It is composed of a main board, based on the famous rp2040 and easy to solder SMD, to which a single, and a double PMOD connector can connect to addons:

- The main board is equipped with a 60Msps, 10bit ADC. Front end is protected against high-voltage pulses, and features a proven time-gain compensation system consisting in a AD8331(55.5dB) with a controlling (MCP4812) SPI DAC. PCB is 4 layers, single face - with only large SMD passives, and no BGA.
- The single PMOD connector can plug to the Pulser board, which can be equipped with a simple +-25V high-voltage (HV) generation board. Together, they generate the pulse on behalf of the pic0rick main board. The setup can generate three-level pulses ( with a pair of MD1210 + TC6320 ). HV board can be swapped easily.
- The double PMOD connector can be used for virtually anything. The current code allows for a VGA to be connected, which displays acquisitions from the board. There is also a 8 MB PSRAM module for more RAM.

The current system uses both PIOs (one for the acquisition, the other for the VGA) which leaves the other resources of the rp2040 relatively free to use for your own priorities.

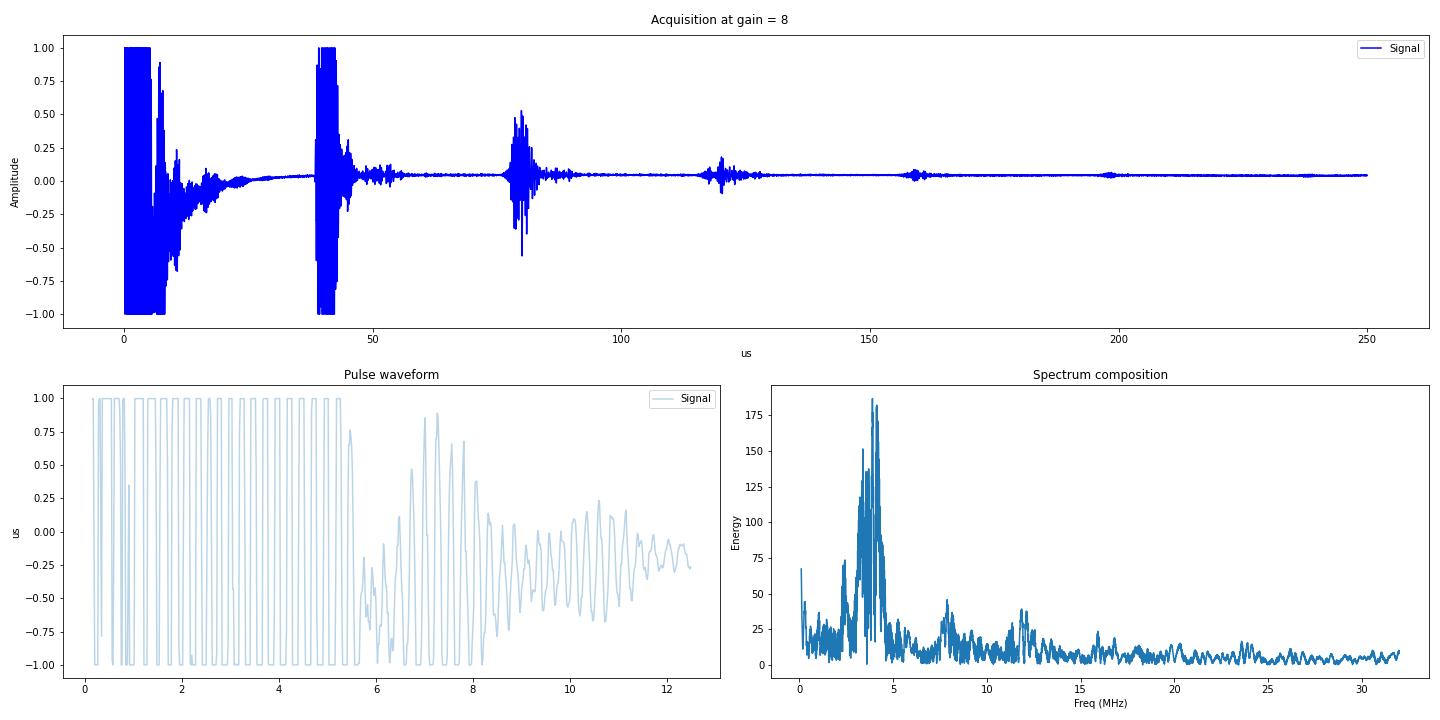
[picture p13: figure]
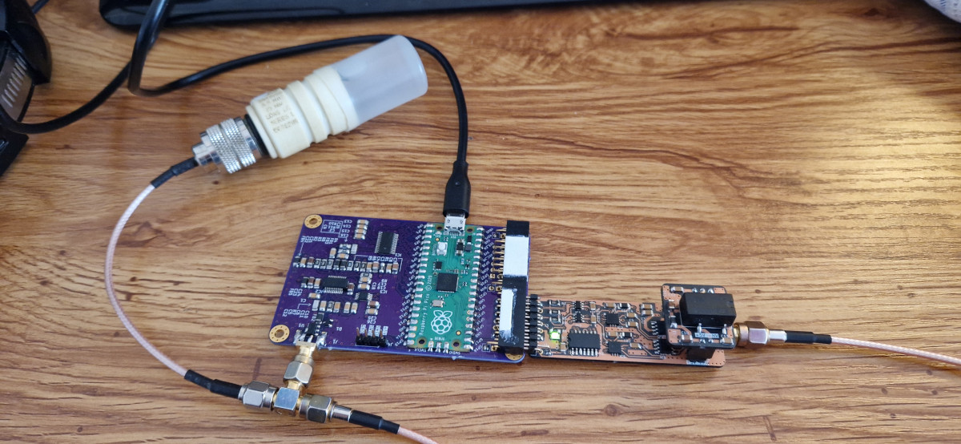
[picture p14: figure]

Figure 1: Setup of the boards (main, pulser, hv) and resulting acquisition. VGA PMOD not connected.

∗More on the website http://un0rick.cc. This paper has its on Zenodo DOI 10.5281/zenodo.10968504 (http://doi.org/10.5281/zenodo.5792252)

PIC0RICK DOCUMENTATION - APRIL 13, 2024

### 2 Where to find the latest sources

The latest sources of the hardware as well as software are available at https://github.com/kelu124/pic0rick/. However, this PDF also doubles as an archive (you can rename the .pdf as a .zip, and you’ll see), and contains, in short: a set of gerbers and BOM, and some documentation. There may be some other stuff there, but I forgot what I put there. Published documents include:

- KiCad design files for the main board
- KiCad design files for the pulser + hv boards
- rp2040 firmware for the microcontroller.

### 3 Next steps

Plenty to do on the next steps. The current shopping list (non-exhaustive) may include:

- Hardware: Slight tweaks on the main board to allow more space for the PMODs, include OSHWA certfication number, ..
- Firmware: Tie the pulses to the PIO code so that pulses strictly cohappen with the acquisition start

### 4 Links to go further

- Come and chat : join the Slack channel (https://join.slack.com/usdevkit/shared_invite/MTkxODU5MjU0NjI1LTE0OTY1ODgxMDEtMmYyZTliZDBlZA)
- The full GitHub repository for the pic0rick "motherboard". (https://github.com/kelu124/pic0rick)
- The board’s Tindie shop (https://www.tindie.com/stores/kelu124/) to get it
- Check out my previous work (http://doi.org/10.5334/joh.28) on the topic of ultrasound modules [4] and its dataset on Zenodo. (http://doi.org/10.5281/zenodo.377054) More to come!

License

This work is based on previous projects, the un0rick, lit3rick and the echOmods projects. The pic0rick project and its boards are open hardware and software, developed with open-source elements.
Copyright Luc Jonveaux / kelu124 (kelu124@gmail.com) 2024
- The hardware is licensed under TAPR Open Hardware License (www.tapr.org/OHL)
- The software components are free software: you can redistribute it and/or modify it under the terms of the GNU General Public License as published by the Free Software Foundation, either version 3 of the License, or (at your option) any later version.
- The documentation is licensed under a Creative Commons Attribution-ShareAlike 3.0 Unported License.

References

[1] Luc Jonveaux 2017. Arduino-like development kit for single-element ultrasound imaging. In Journal of Open Hardware, 1(1), p.3. DOI: 10.5334/joh.2 (http://doi.org/10.5334/joh.2)
[2] Luc Jonveaux 2019. un0rick : open-source fpga board for single element ultrasound imaging On Zenodo. DOI: 10.5281/zenodo.3364559 (http://doi.org/10.5281/zenodo.3364559)
[3] Luc Jonveaux 2021. lit3rick: an up5k ultrasound pulse-echo device On Zenodo. DOI: 10.5281/zenodo.5792245 (http://doi.org/10.5281/zenodo.5792245)
[4] Luc Jonveaux, Carla Schloh, William Meng, Jorge Arija, Jean Rintoul 2024. Review of Current Simple Ultrasound Hardware Considerations, Designs, and Processing Opportunities On Journal of Open Hardware (JOH) . DOI: 10.5334/joh.28 (http://doi.org/10.5334/joh.28)
[5] Luc Jonveaux 2021. An opensource max14866 development board On Zenodo. DOI: 10.5281/zenodo.5792252 (http://doi.org/10.5281/zenodo.5792252)

2

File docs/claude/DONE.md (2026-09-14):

# DONE — pic0rick

Completed actions, most recent first. Items are moved here from `TODO.md` when
finished. Each entry links to its commit log in `docs/claude/commits/`.

---

## 2026-09-14

- **README refresh (on main).** Quick start + command tables updated for the DSP
  build (stdio commands no longer the default), pulser pins fixed, Repository
  layout table added. API references verified against code. See
  `commits/2026-09-14-readme-refresh.md`.

- **example_simple + ndt_acquisition on the DSP CLI (py v0.1.8).** New
  `Pic0rick.set_gain/configure_pulse/arm_pulser/disarm_pulser`; `example_simple.ipynb`
  and `ndt_acquisition.from_probe()` now use `read_raw` (binary) instead of the
  stdio hex path. Hardware-verified (from_probe echoes present). See
  `commits/2026-09-14-example-simple-ndt-dsp-cli.md`.

- **example_dsp.ipynb: A-law + self-test + file saving, armed from start (py v0.1.7).**
  A-law decode-vs-envelope plot, DSP self-test summary, pulser-order check,
  per-capture saving to `captures/<name>/`. Hardware-verified. See
  `commits/2026-09-14-dsp-notebook-alaw-selftest-save.md`.

- **DSP notebook shows Pico text replies + us times (py v0.1.6).** Added
  `dsp.describe_status()`, `status()['raw']`, `capture().last_reply`; the notebook
  now prints version/status/OK replies and per-stage DSP µs. Hardware-verified.
  See `commits/2026-09-14-dsp-notebook-show-replies.md`.
- **docs/fw_history convention.** README for the maintainer-curated firmware
  baseline archive; rule that only the maintainer adds `.uf2` there (Claude never
  does). See `commits/2026-09-14-fw-history-convention.md`.

## 2026-09-13

- **MUX/pulser PIO1 SM conflict fix — echoes restored (fw v0.1.11).**
  `max14866_init` hardcoded pio1 sm0, clobbering the pulser drive SM; now claims
  an unused SM. Verified on the user's piezo: mux build echo `var[2000:3000]`
  0.4 → ~52k (matches v0.1.1 baseline). Root cause of the "no echo" report. See
  `commits/2026-09-13-mux-pulser-sm-conflict-fix.md`.
- **Pulser echo regression fix (fw v0.1.10).** `queue_pulse` now fires the
  bipolar pulse back-to-back then damps (was: damp between polarities, a P4b
  regression that killed echoes). Not OE (that's correct/active-high). Transmit
  confirmed strong on hardware; echo-vs-target left to the user's setup. See
  `commits/2026-09-13-pulser-echo-fix.md`.
- **DSP example notebook + DAC fix (py v0.1.5).** `python/example_dsp.ipynb`
  (step-by-step, executed via nbconvert on hardware); fixed the DSP DAC command
  (`dac write`). See `commits/2026-09-13-dsp-example-notebook.md`.
- **DSP test guide + example + firmware CHANGELOG (py v0.1.4).**
  `docs/dsp_test_guide.md` + `python/example_dsp.py` (new API, hardware-tested);
  `firmware/CHANGELOG.md` created and made a rule (update on every fw bump). See
  `commits/2026-09-13-dsp-guide-example-changelog.md`.
- **P8 — docs consolidation; unification complete.** README building/DSP
  sections + command table; plan marked done (P0–P8). Firmware v0.1.9, python
  v0.1.3, on `feature/unify-firmware-dsp` (not merged). See
  `commits/2026-09-13-p8-docs.md`.
- **P7 — retire experiments/onboard_dsp (py v0.1.3).** Removed `experiments/`;
  kept the format spec as `docs/dsp_output_formats.md`; fixed all references.
  See `commits/2026-09-13-p7-retire-onboard-dsp.md`.
- **P6 — 6-variant build matrix + CI (fw v0.1.9).** build.sh builds all 6
  (adds rp2350 mux/nomux +DSP) into dist/ with a shared CMSIS-DSP cache; CI
  caches it and releases all 6. See `commits/2026-09-13-p6-build-matrix-ci.md`.
- **P5 — DSP host protocol in python (py v0.1.2).** `pic0rick/dsp.py`
  (length-agnostic frame reader + CRC + status parser) and
  `Pic0rick.status()/capture()/read_fft()/read_raw()`; dropped the hard version
  gate. Verified on hardware. See `commits/2026-09-13-p5-host-dsp-protocol.md`.
- **P4b — unified HW drivers (fw v0.1.8).** Moved acquisition+pulser+spi1 DAC to
  shared `firmware/hw/`; stdio build now uses them (raw 8000); retired `adc/` +
  `max/dac.c`. Verified on RP2350 hardware. See
  `commits/2026-09-13-p4b-unify-hw-drivers.md`.
- **P4a — two-length acquisition (fw v0.1.7).** `read_raw` (8000, raw) /
  `read_fft` (4096, envelope); per-job sample_count threaded through
  acquisition/pipeline/dsp. Verified frame sizes on RP2350A hardware. See
  `commits/2026-09-13-p4a-two-length-reads.md`.
- **P3 — runnable DSP build (fw v0.1.6).** `main_dsp.c` raw-TinyUSB command loop
  (DSP builds; stdio OFF) with version/reboot-dfu/mux; non-DSP stdio unchanged.
  Verified on RP2350A hardware (version/help/status + `acq raw` 8256-B frame);
  DSP+noMUX and default variants build. See
  `commits/2026-09-13-p3-dsp-command-loop.md`.
- **P2 — land onboard-DSP modules (fw v0.1.5).** Copied sources to
  `firmware/dsp/`; built the USB-free set as `p0rk_dsp` static lib under
  `if(DSP)`. USB transport deferred to P3. Default builds unchanged;
  `libp0rk_dsp.a` verified. See `commits/2026-09-13-p2-land-dsp-modules.md`.
- **P1 — `-DDSP` scaffolding + CMSIS-DSP (fw v0.1.4).** pico2-guarded DSP option
  and `cmsisdsp_p0rk` lib; no sources yet, default builds unchanged. Verified
  guard + CMSIS-DSP fetch/build. See `commits/2026-09-13-p1-dsp-scaffolding.md`.
- **P0 — SDK bump to 2.3.0 (fw v0.1.3).** CMakeLists + CI workflow ref; all 4
  variants build; rp2350 flashed + confirmed on hardware. First phase of the
  onboard-DSP unification. See `commits/2026-09-13-p0-sdk-2.3.0.md`.
- **`reboot-dfu` command + hardware test (fw v0.1.2).** Added `reboot-dfu`
  (reset_usb_boot → BOOTSEL). Flashed and verified on a real RP2350A/Pico 2 W:
  `version` + the flash→run→`reboot-dfu`→BOOTSEL loop. New `hardware-testing.md`.
  See `commits/2026-09-13-reboot-dfu.md`. (branch feature/unify-firmware-dsp)
- **Python parses the firmware `version` command (py v0.1.1).**
  `Pic0rick.version()` queries `version` and returns a parsed dict. See
  `commits/2026-09-13-python-version-parse.md`.
- **`version` command build metadata + dual-version release notes (fw v0.1.1).**
  `version` now prints board/chip, git build hash (`-dirty` aware) and the
  release URL; CI release body lists both firmware + python versions. See
  `commits/2026-09-13-version-metadata.md`.
- **Firmware `version` command + versioning.** `firmware/version.yaml` (A.B.C +
  changes) → CMake-generated `version.h` → `version` CLI command. Firmware v0.1.0.
  See `commits/2026-09-13-firmware-version-mux-ci.md`.
- **MUX made optional at compile time (`-DMUX`).** Split the gain DAC out to
  `max/dac.c` (always built); `max/max14866.c` + mux commands gated by `-DMUX`.
  Same commit log.
- **CI build + release workflow.** `.github/workflows/firmware.yml` builds all 4
  variants (rp2040/rp2350 × mux/nomux), uploads artifacts, and releases on push
  to main. `build.sh` now builds all 4 into `dist/`. Same commit log.
- **Python library versioning.** `python/pic0rick/__init__.py` +
  `version.yaml` expose `pic0rick.__version__`, v0.1.0. See
  `commits/2026-09-13-python-versioning.md`.

## 2026-09-12

- **hardware: panel_adc_pulser_hv board.** Registered the new
  `panel_adc_pulser_hv` board (`3_in_1_Panel`) in `hardware/build.sh` and
  generated its JLCPCB production outputs. See
  `commits/2026-09-14-hardware-panel-adc-pulser-hv.md`.

- **Firmware↔Python command parity.** Audited the 6 firmware serial commands
  against `python/pic0rick`; added the 3 missing MUX methods (`write_mux`,
  `set_mux`, `clear_mux`) to `Pic0rick`. See
  `commits/2026-09-12-mux-command-parity.md`.
- **Set up task tracking.** Created `docs/claude/TODO.md`, this file, and the
  `docs/claude/commits/` log folder; transformed `QUESTIONS.md` into TODO actions
  and removed it. See `commits/2026-09-12-setup-todo-tracking.md`.

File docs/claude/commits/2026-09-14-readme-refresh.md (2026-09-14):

# 2026-09-14 — README refresh (post-unification), on main

Docs only. Committed directly to `main` (post-merge) at the user's request.

## What
- **Quick start** rewritten for the DSP build: `set_gain` + `configure_pulse` +
  `arm_pulser` + `read_raw()` (the old `dac`/`pulse_adc_trigger`/`read` were
  stdio-only and don't transmit on the DSP build the board runs). Notes the stdio
  alternative; `from_probe` example kept (it drives the DSP build internally).
- **Serial command reference** relabelled as the stdio/non-DSP build; fixed the
  mux rows (`write mux <hex>`, `set/clear mux` take no arg); pointer to the DSP
  build's command set.
- **DSP build** section: added `dac write` / `pulse config` / `pulser` commands
  and the `Pic0rick` helper list; links to the test guide + notebooks.
- **Signal chain**: pulser pins corrected to GPIO11/12 (P+/P-) + GPIO16/17
  (PDAMP/OE), MD1213.
- Added a **Repository layout** table (firmware/, python/, hardware/, docs/,
  .github/workflows/).

## Verification
Checked every README Python reference against the code (`.venv`): all
`Pic0rick` methods exist, `from_probe` signature matches, `pic0rick.dsp` helpers
present.

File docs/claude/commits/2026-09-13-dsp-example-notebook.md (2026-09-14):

# 2026-09-13 — DSP example notebook + DAC command fix

Python library **v0.1.5**. Branch `feature/unify-firmware-dsp`.

## What
- Added `python/example_dsp.ipynb` — a step-by-step notebook version of
  `example_dsp.py` (imports → connect → status → set gain → read_raw → read_fft →
  pulsed read_fft → optional save), with inline matplotlib plots.
- **Bug fix:** the DSP firmware's DAC command is `dac write <n>`, not the stdio
  build's `write dac <n>`. `example_dsp.py` (and the notebook) used
  `probe.dac()` / `write dac`, which the DSP build rejected with
  `ERR COMMAND unknown command` — the gain was silently not set. Both now send
  `dac write <n>` over serial.

## Verified on hardware (RP2350A, DSP v0.1.9)
Executed the notebook with `jupyter nbconvert --execute`:
- DAC cell now returns `OK dac=300` (was ERR); the gain visibly raises the raw
  mean (397 → 563).
- status, read_raw (8000 u16), read_fft (4096 f32), and the pulsed capture
  (idle peak 63.6 → pulsed 181.0) all succeed; 3 plots render; no errors.
- `example_dsp.py` carries the same fix.

## Notes
- Notebook uses `nbformat_minor: 4` (no per-cell id warning).
- Running the notebook writes `raw.npy` / `envelope.npy` into `python/` (the
  optional save cell) — local artifacts, not committed.

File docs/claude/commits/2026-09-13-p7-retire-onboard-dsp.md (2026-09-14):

# 2026-09-13 — P7: retire experiments/onboard_dsp

Python library **v0.1.3** (docs/reference edits only). Branch
`feature/unify-firmware-dsp`.

## What
- **Removed `experiments/` entirely** (50 tracked files: the onboard_dsp
  firmware, tools, notebook, captures, and the empty top-level Readme).
- **Kept** the durable format reference: `understanding_figures.md` →
  `docs/dsp_output_formats.md` (updated its parsing-helpers section to point at
  `pic0rick.dsp` + the device methods; added a "spec now describes the -DDSP
  build" note).
- **Dropped** `test_guide.md`, `DSP_Tests.ipynb`, `tools/pic0rick_capture.py`,
  `tools/requirements.txt`: all tightly coupled to the removed capture CLI and
  superseded by the `pic0rick.dsp` library. A fresh test guide + example notebook
  are logged in `docs/claude/TODO.md`.
- **Reference fixes:** `CLAUDE.md` (topic list + tree), `docs/claude/README.md`,
  `docs/claude/firmware.md` (unified-tree intro + build flavours section),
  `docs/claude/python-host-tools.md`, `python/Readme.md`, `python/pic0rick/dsp.py`
  docstring. Rewrote `docs/claude/onboard-dsp-firmware.md` as a "retired / where
  it went" pointer.

## Verification
`check-links --no-external`: 5 flagged local refs are all false positives (regex
strings in `.py`, and vendored CMSIS-DSP under `firmware/.deps/`). No genuine
broken references from the removal.

## Result
"One firmware, not two": the DSP firmware now lives only in the mainline
`firmware/` tree (`-DDSP`), and there is a single host stack in `python/`.

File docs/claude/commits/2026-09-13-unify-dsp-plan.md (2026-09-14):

# 2026-09-13 — Migration plan: unify onboard_dsp into firmware (branch)

Branch `feature/unify-firmware-dsp`. Docs only — no code, no version bump.

## What
Added `docs/claude/unify-firmware-dsp-plan.md`: an 8-phase plan to fold the
`experiments/onboard_dsp/` DSP features into `firmware/` behind a `-DDSP` flag
(RP2350 only), retiring onboard_dsp when done.

## Why
User confirmed the approach (fold + gate + CLI commands + SDK 2.3.0 + retire)
and asked for a plan.

## Key finding driving the plan
onboard_dsp uses **raw TinyUSB** (SDK stdio disabled) so text + binary frames
share one CDC; the mainline REPL uses SDK stdio. Only one USB stack can own the
CDC, so the unified firmware must choose. Recommended **Design A**: the DSP build
adopts onboard_dsp's raw-TinyUSB transport + its (already CLI-shaped) command
loop; RP2040 keeps SDK stdio. Awaiting user confirmation on this and 3 other
open items (DAC unify, pulser pin map, version handshake) before Phase 3/4.

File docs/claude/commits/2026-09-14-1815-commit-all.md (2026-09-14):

# 2026-09-14 18:15 — scheduled commit-all

Committed all pending working-tree changes and pushed to
feature/unify-firmware-dsp, per the user's 18:15 request.

```
?? docs/claude/commits/2026-09-14-1815-commit-all.md
```

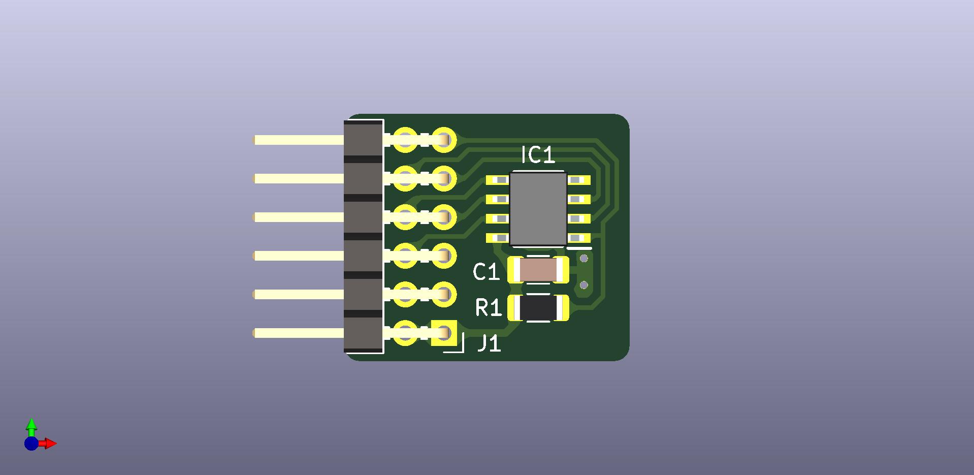
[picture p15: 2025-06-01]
hardware/psram/viewme.jpg

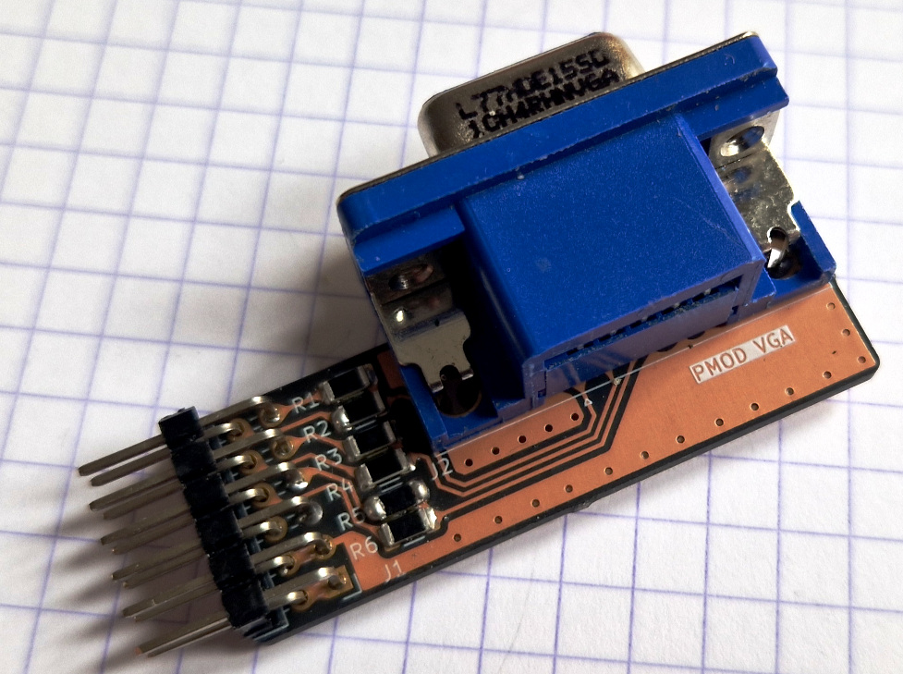
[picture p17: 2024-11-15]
hardware/vga/built.jpg

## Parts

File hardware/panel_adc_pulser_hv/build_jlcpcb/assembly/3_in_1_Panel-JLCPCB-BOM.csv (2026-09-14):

Comment | Designator | Footprint | MPN | Manufacturer | LCSC Part #
22pF | C12 | C_1206_3216Metric | VJ1206A220JXQPW1BC
50pF | C20 | C_1206_3216Metric | 12062A500KAT2A | KYOCERA AVX
1nF | C18,C21,C23 | C_1206_3216Metric | GRM31C5C3A102JWA3L
10nF | C29,C30,C31 | C1206 | FCC1206B103K500DT | FOJAN(富捷)
18nF | C6 | C_1206_3216Metric | VJ1206Y183KXAAC
100nF | C1,C2,C4,C5,C8,C9,C10,C11,C13,C14,C15,C16,C17,C19,C22,C24,C26 | C_1206_3216Metric | VJ1206Y104KXQCW1BC
100nF | C27,C28,C32,C33,C36,C37,C38 | C1206 | CL31B104KBCNNNC | SAMSUNG(三星)
1uF | C34,C35,C39,C42 | C1206 | CL31B105KBHNNNE | SAMSUNG(三星)
4.7uF | C3,C7 | C_1206_3216Metric | 1206ZD475KAT4A
4.7uF | C40,C41 | C1206 | UMK316AB7475KL-T | TAIYO YUDEN(太诱)
10uF | C25 | C_1206_3216Metric | KAF31GR71C106KU | KYOCERA AVX
BAV99 | D2 | SOT-23-3_L2.9-W1.3-P1.90-LS2.4-BR | BAV99 | DIODES(美台)
BAV99 | D4 | SOT-23-3_L2.9-W1.3-P1.90-LS2.4-BR | BAV99-7-F | DIODES(美台)
BAV99-7-F | D1 | SOT95P240X120-3N | BAV99-7-F
Green LED | D3 | LED0805-R-RD | NCD0805G1 | 国星光电
120Ohm 3 A | FB6,FB7 | L1206 | CBW321609U121T | FH(风华)
ILHB1206ER750V | FB1,FB2,FB3,FB4,FB5 | L_1206_3216Metric | BLM21BB750SN1D
TC74VHC08F_EL,K,F_ | H1 | SOP-14_L10.2-W5.3-P1.27-LS7.8-BL | TC74VHC08F_EL,K,F_ | TOSHIBA(东芝)
AD8331ARQZ | IC2 | SOP64P600X175-20N | MD1213K6-G
ADC10065CIMT_NOPB | IC1 | SOP65P640X120-28N | SN74LVC2G04DBVT
MCP4812-E_MS | IC3 | MCP4812-EMS | 579-MCP4812-E/MS
MD1213K6-G | IC4 | QFN-12_L4.0-W4.0-P0.80-BL-EP1.7 | SN74LVC2G04DBVT | MICROCHIP(美国微芯)
MD1213K6-G | IC5 | QFN-12_L4.0-W4.0-P0.80-BL-EP1.7 | MD1213K6-G | MICROCHIP(美国微芯)
SN74LVC2G04DBVT | IC6 | SOT-23-6_L2.9-W1.6-P0.95-LS2.8-BR | TC6320TG-G | TI(德州仪器)
SN74LVC2G04DBVT | IC9 | SOT-23-6_L2.9-W1.6-P0.95-LS2.8-BR | SN74LVC2G04DBVT | TI(德州仪器)
TC6320TG-G | IC7,IC8 | SOIC-8_L4.9-W3.9-P1.27-LS6.0-BL | TC6320TG-G | MICROCHIP(美国微芯)
61300411121 | J4 | PinHeader_1x04_P2.54mm_Vertical | 61300411121
61300611021 | J9 | HDR-TH_6P-P2.54-H-M-W10.3 | HX PZ2.54-1x6P WZ | hanxia(韩下)
61300611121 | J3 | PinSocket_1x06_P2.54mm_Horizontal | 61300611021
90122-0126 | J6 | PinSocket_2x06_P2.54mm_Horizontal | 613012243121
AMPHENOL_132357-11 | J1 | AMPHENOL_132357-11 | 132357-11
Conn_01x02 | J8 | HDR-TH_2P-P2.54-H-M-R2-C1_TSW-101-08-XXX-D-RA | HTSW-101-08-T-D-RA | SAMTEC
Conn_01x02_Pin | J11 | HDR-TH_2P-P2.54-V-M | PZ254V-11-02P | XFCN(兴飞)
Conn_01x02_Socket | J13 | HDR-TH_2P-P2.54-V-F | ZX-PM2.54-1-2PY | Megastar(兆星)
Conn_01x03_Pin | J10 | HDR-TH_3P-P2.54-V-M_PZ254V-11-03P | PZ254V-11-03P | XFCN(兴飞)
Conn_01x03_Socket | J14 | HDR-TH_3P-P2.54-V-F | HC-PM254-8.5H-1x3PZ-02A | HC(虹成电子)
SSQ-101-02-L-Q-RA | J2,J5,J7 | PinHeader_1x02_P2.54mm_Vertical | SSQ-101-02-L-Q-RA
6.8uH | L1 | L1206 | ILSB1206ER6R8K | VISHAY(威世)
R2D-0524_P | PS1 | PWRM-SMD_R2D-XXXX | R2D-0524 | Recom Power
18R | R1,R10,R11 | R_1206_3216Metric | WSL1206R1800FEA
100R | R4,R8 | R_1206_3216Metric | 560112132023
280R | R7 | R_1206_3216Metric | CR1206-FX-2800ELF | Bourns
1K | R12 | R1206 | FRC1206J102 TS | FOJAN(富捷)
10K | R13,R14,R15 | R1206 | FRC1206F1002TS | FOJAN(富捷)
10K | R2,R3,R5,R6 | R_1206_3216Metric | 1206W4F1002T5E
12K | R9 | R_1206_3216Metric | CR1206-FX-1202ELF | Bourns
MD0100N8-G | U1 | SOT-89-3 | MD0100N8-G
Pico | U2 | RPi_Pico_SMD | Pico
VAL** | mouse-bite-3mm-slot | mouse-bite-3mm-slot

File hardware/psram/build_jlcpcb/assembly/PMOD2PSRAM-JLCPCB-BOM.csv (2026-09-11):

Comment | Designator | Footprint | MPN | Manufacturer | LCSC Part #
100nF | C1 | C_1206_3216Metric
APS6404L-3SQR-SN | IC1 | SOIC127P600X175-8N
Conn_02x06_Odd_Even | J1 | PinHeader_2x06_P2.54mm_Horizontal
10K | R1 | R_1206_3216Metric

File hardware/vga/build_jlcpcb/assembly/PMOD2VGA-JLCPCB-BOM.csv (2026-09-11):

Comment | Designator | Footprint | MPN | Manufacturer | LCSC Part #
Conn_02x06_Odd_Even | J1 | PinHeader_2x06_P2.54mm_Horizontal
DE15_Receptacle_HighDensity_MountingHoles | J2 | DSUB-15-HD_Female_Horizontal_P2.29x1.98mm_EdgePinOffset3.03mm_Housed_MountingHolesOffset4.94mm
400 | R1,R2,R3,R4,R5,R6 | R_1206_3216Metric

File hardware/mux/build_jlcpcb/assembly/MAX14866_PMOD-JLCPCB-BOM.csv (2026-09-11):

Comment | Designator | Footprint | MPN | Manufacturer | LCSC Part #
100nF | C3 | C_1206_3216Metric
1uF | C2 | C_1206_3216Metric
22-23-2021 | J6 | PinSocket_2x01_P2.54mm_Horizontal | 22-23-2021
22-23-2021 | J7 | PinHeader_2x01_P2.54mm_Horizontal | 22-23-2021
90122-0126 | J2 | PinHeader_2x06_P2.54mm_Horizontal | 90122-0126
90122-0126 | J4 | PinSocket_2x06_P2.54mm_Horizontal | 90122-0126
AMPHENOL_132357-11 | J1,J3 | AMPHENOL_132357-11-MOD | AMPHENOL_132357-11
Conn_02x08_Odd_Even | J5 | PinHeader_2x08_P2.54mm_Vertical
10R | R1 | R_1206_3216Metric
10K | R2,R3 | R_1206_3216Metric
MAX14866UTM+T | U2 | 21-0144H_T4877-6_MXM

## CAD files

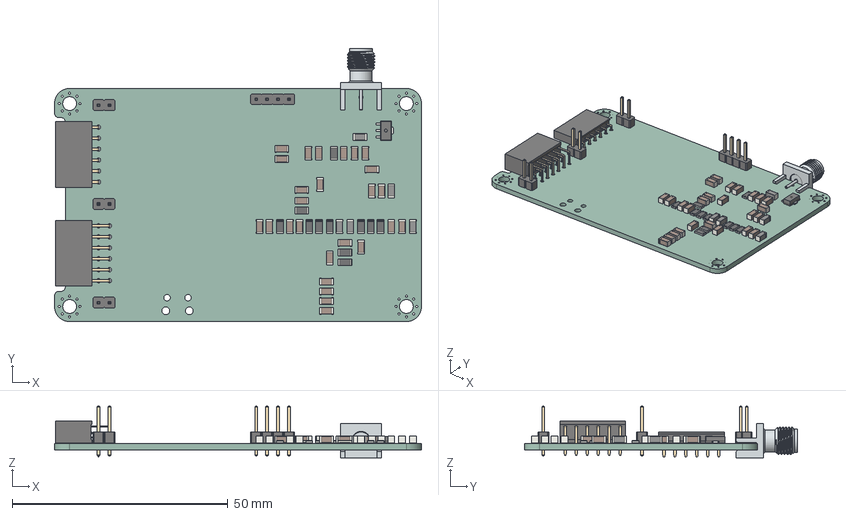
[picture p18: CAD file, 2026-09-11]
hardware/adc/build_jlcpcb/3D/PICO_ADC_Test.step
85.0 x 63.3 x 12.0 mm
C_1206_3216Metric x 26
R_1206_3216Metric x 11
L_1206_3216Metric x 5
PinHeader_1x04_P254mm_Vertical
PinHeader_1x02_P254mm_Vertical x 3
PinSocket_1x06_P2.54mm_Horizontal
adbeea57-9c39-11ed-93f0-dde97e994e83_part
adbeea58-9c39-11ed-93f0-dde97e994e83_part
adbeea59-9c39-11ed-93f0-dde97e994e83_part
PinSocket_2x06_P2.54mm_Horizontal
kibot_x9ziy3oj_PCB

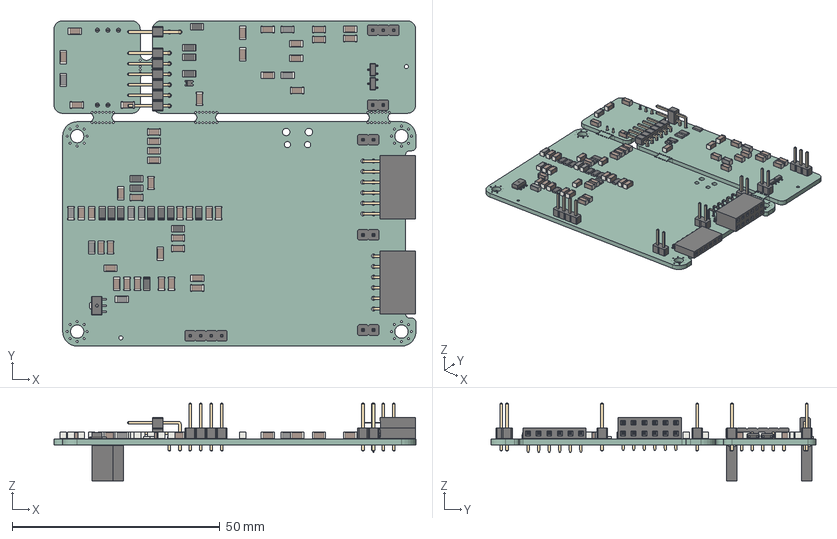
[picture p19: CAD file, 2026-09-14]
hardware/panel_adc_pulser_hv/build_jlcpcb/3D/3_in_1_Panel.step
87.1 x 78.2 x 18.7 mm
R_1206_3216Metric x 15
C_1206_3216Metric x 42
PinHeader_1x04_P254mm_Vertical
L_1206_3216Metric x 8
PinHeader_1x02_P254mm_Vertical x 4
PinSocket_2x06_P2.54mm_Horizontal
D_0805
SOT-23 x 2
adbeea57-9c39-11ed-93f0-dde97e994e83_part
adbeea58-9c39-11ed-93f0-dde97e994e83_part
adbeea59-9c39-11ed-93f0-dde97e994e83_part
PinHeader_1x03_P254mm_Vertical
PinHeader_2x01_P254mm_Horizontal
PinHeader_1x06_P254mm_Horizontal
PinSocket_1x06_P2.54mm_Horizontal
PinSocket_1x02_P2.54mm_Vertical
PinSocket_1x03_P2.54mm_Vertical
3_in_1_Panel_PCB

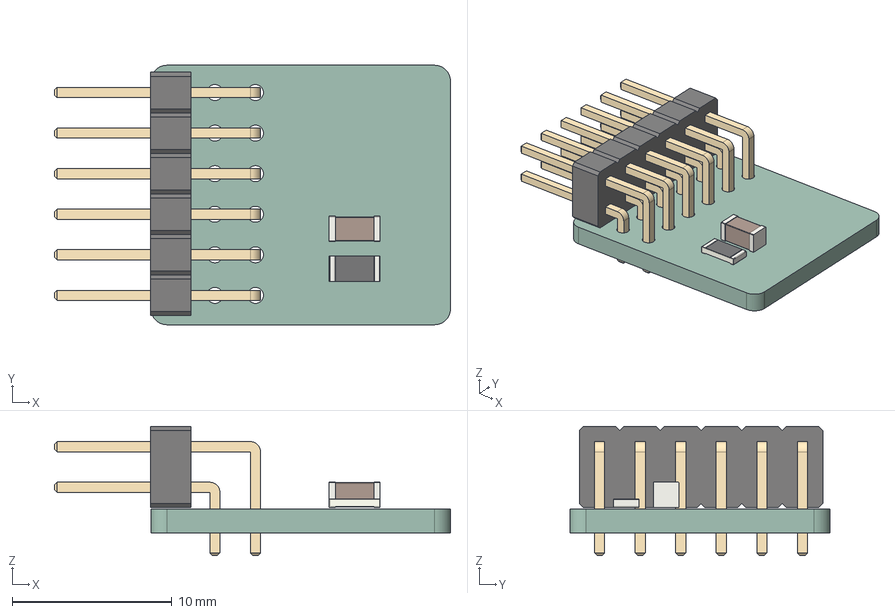
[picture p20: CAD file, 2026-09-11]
hardware/psram/build_jlcpcb/3D/PMOD2PSRAM.step
24.8 x 16.2 x 8.08 mm
C_1206_3216Metric
R_1206_3216Metric
PinHeader_2x06_P254mm_Horizontal
kibot_omhnx48o_PCB

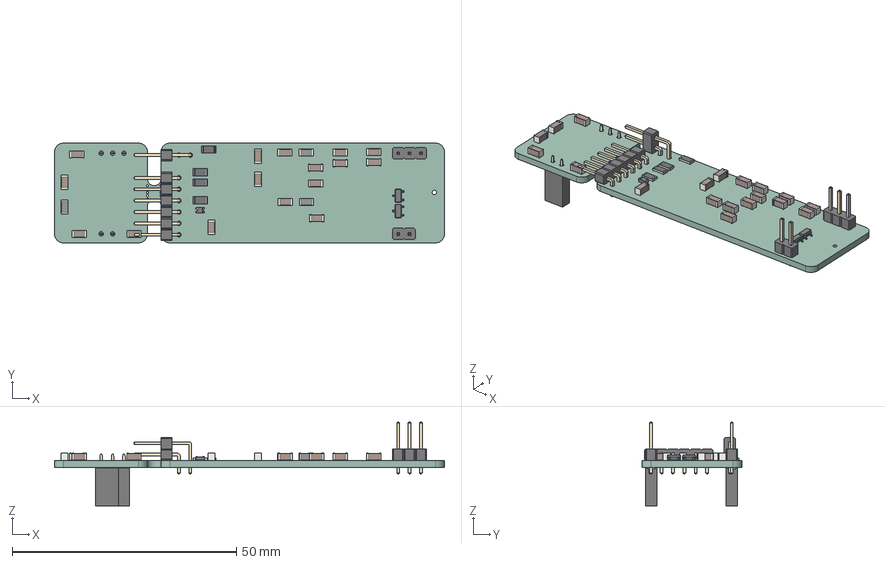
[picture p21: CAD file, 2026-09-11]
hardware/pulser_panel/build_jlcpcb/3D/panel.step
87.0 x 22.2 x 18.7 mm
C_1206_3216Metric x 16
PinHeader_1x06_P254mm_Horizontal
L_1206_3216Metric x 3
PinHeader_2x01_P254mm_Horizontal
PinHeader_1x02_P254mm_Vertical
SOT-23 x 2
D_0805
PinHeader_1x03_P254mm_Vertical
R_1206_3216Metric x 4
PinSocket_1x03_P2.54mm_Vertical
PinSocket_1x02_P2.54mm_Vertical
kibot_dkg4z8lg_PCB

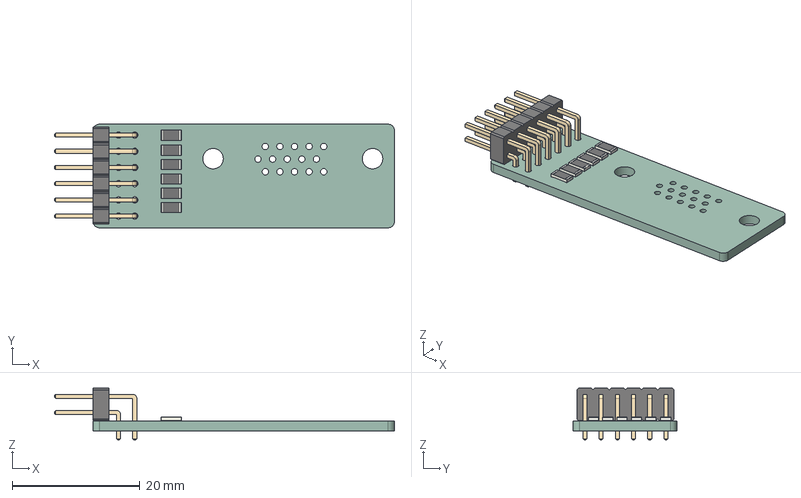
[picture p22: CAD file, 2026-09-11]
hardware/vga/build_jlcpcb/3D/PMOD2VGA.step
53.3 x 16.2 x 8.08 mm
R_1206_3216Metric x 6
PinHeader_2x06_P254mm_Horizontal
kibot_mp4bxgom_PCB

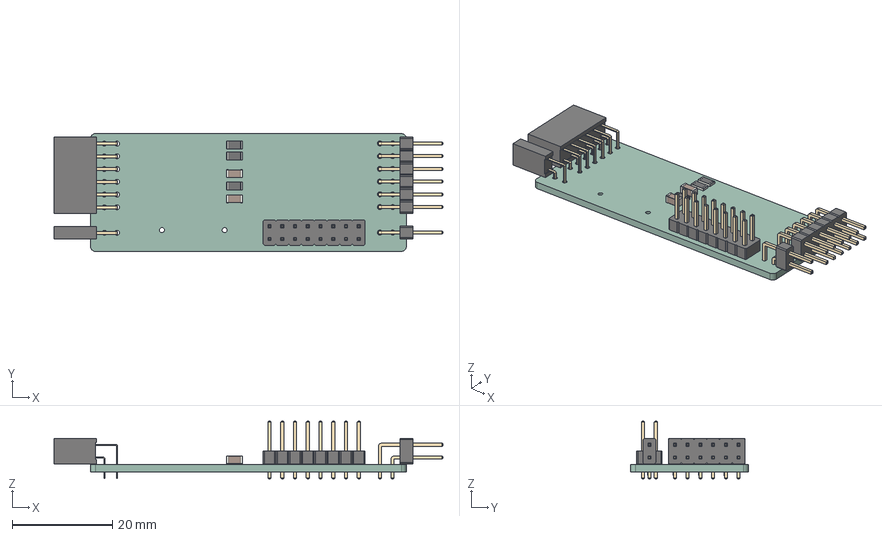
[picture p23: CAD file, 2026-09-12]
hardware/mux/build_jlcpcb/3D/MAX14866_PMOD.step
77.6 x 23.5 x 11.5 mm
R_1206_3216Metric x 3
PinHeader_2x01_P254mm_Horizontal
PinHeader_2x06_P254mm_Horizontal
PinSocket_2x01_P2.54mm_Horizontal
C_1206_3216Metric x 2
PinSocket_2x06_P2.54mm_Horizontal
PinHeader_2x08_P254mm_Vertical
kibot_j_7izcvn_PCB

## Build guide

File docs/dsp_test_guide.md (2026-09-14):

# pic0rick DSP firmware — test guide

How to build, flash and exercise the **`-DDSP`** firmware (RP2350 on-board
Hilbert-envelope DSP + binary protocol). For the frame/status wire formats see
[`dsp_output_formats.md`](dsp_output_formats.md); for the host API see
[`claude/python-host-tools.md`](claude/python-host-tools.md).

## 1. Build

```bash
cd firmware && ./build.sh          # all 6 variants -> firmware/dist/
# the DSP UF2s are:
#   dist/pic0rick-v<ver>-rp2350-mux-dsp.uf2
#   dist/pic0rick-v<ver>-rp2350-nomux-dsp.uf2
```
(Or build just one: `cmake -B build -DPICO_BOARD=pico2 -DDSP=ON && cmake --build build`.)

## 2. Flash

1. Enter the bootloader: hold **BOOTSEL** while plugging in USB, **or** — if a
   pic0rick firmware (≥ v0.1.2) is already running — send `reboot-dfu` over
   serial. The board mounts as an `RP2350` mass-storage drive.
2. Copy the DSP UF2 onto it; the board reboots and enumerates as a USB-CDC port
   (`/dev/ttyACM*` on Linux).

## 3. Talk to it — serial

The DSP build replies with `OK …` / `ERR …` text lines and streams binary frames
for captures. Useful commands:

| Command | Effect |
|---|---|
| `version` | firmware version, board/chip, options, git hash, release URL |
| `status` | one-line machine-readable state (see dsp_output_formats.md) |
| `help` | list all commands |
| `read_raw` | capture 8000 raw ADC samples → one raw frame |
| `read_fft` | capture 4096-sample Hilbert envelope → one envelope frame |
| `acq raw\|envelope\|alaw` | one capture of the given type |
| `dsp selftest` | stream the deterministic self-test vectors |
| `dsp scale <ref>` | set the A-law full-scale reference |
| `pulser arm` / `pulser disarm` | enable/disable firing on capture |
| `pulse config <neg_ns> <damp_ns> <pos_ns> <neg-first\|pos-first>` | pulse timing |
| `write dac <0..1023>` | set TGC gain (spi1 MCP4812) |
| `reboot-dfu` | reboot into the bootloader for reflashing |

Because captures are **binary** frames, don't parse them by hand in a plain
terminal — use the Python host below.

## 4. Talk to it — Python

```python
from pic0rick.device import Pic0rick
p = Pic0rick(verbose=False)          # auto-detects the port

print(p.status())                    # parsed dict: firmware, samples, pulser, ...

frame = p.read_fft()                 # 4096-sample Hilbert envelope
env = frame.samples()                # numpy float32[4096]; CRC already checked
print("envelope peak", env.max())

raw = p.read_raw().samples()         # numpy uint16[8000]
```

`p.capture("raw"|"envelope"|"alaw")` is the general form; `read_raw()` /
`read_fft()` are shortcuts. Frame metadata is on `frame.header`
(`sample_count`, `payload_bytes`, `adc_dc_mean`, `envelope_peak`, `pulse`, …).
A-law payloads can be expanded with `pic0rick.dsp.alaw_decode(bytes, reference)`.

## 5. Run the example

`python/example_dsp.py` ties it together (status → read_raw → read_fft →
a pulsed capture):

```bash
cd python
python example_dsp.py                 # summary to stdout
python example_dsp.py --save out/     # + raw.npy / envelope.npy
python example_dsp.py --plot out/     # + capture.png (needs matplotlib)
```

For an interactive, step-by-step version, open the notebook
`python/example_dsp.ipynb` and run the cells top to bottom (set `PORT` in cell 2).
It arms the pulser from the start and covers **raw / Hilbert envelope / A-law**
(with `alaw_decode` overlaid on the envelope), the **DSP self-test**, a
**pulser-order** check, shows every Pico text reply + per-stage DSP µs times, and
**saves each capture** to `captures/<name>/` (`<payload>.npy` + `header.json` +
`status.txt`). `captures/` is gitignored.

Expected output resembles:

```
Board: pic0rick RP2350A | firmware 0.1.9 | backend f32-rfft-hilbert
Captures (pulser disarmed):
  read_raw  type=raw      samples= 8000 bytes=16000 seq=...
            min/mean/max = .../.../...
  read_fft  type=envelope samples= 4096 bytes=16384 seq=...
            envelope peak=... dc_mean=...
Captures (pulser armed):
  read_fft  type=envelope samples= 4096 ...
```

## 6. Self-test (optional)

`dsp selftest` streams 7 cases × 3 payload types (raw/envelope/A-law) of known
synthetic vectors — a firmware-only integrity check of the DSP pipeline. Read the
frames with a `pic0rick.dsp.FrameReader(p.ser)` loop; each frame's
`header.selftest_case` identifies the vector.

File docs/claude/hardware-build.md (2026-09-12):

# Hardware production outputs — `hardware/build.sh`

Generates JLCPCB-friendly production artefacts from the KiCad boards under
`hardware/<board>/` using **KiBot** + **kicad-cli**. Output lands in
`hardware/<board>/build_<vendor>/` (vendor = config basename, so the default
`jlcpcb.kibot.yaml` → `build_jlcpcb/`), split into `gerbers/`, `production/`,
`assembly/`, and `3D/` subfolders.

## Usage

```bash
./build.sh [board_dir|all] [group]
```

- `board_dir`: `adc` (default), `mux`, `psram`, `vga`, `pulser_panel`, or `all`
  (every board in the `BOARDS` registry). Accepts `hardware/mux` or an abs path too.
- `group` (default `all`) — what to build. **3D deliverables (STEP + top &
  bottom PNG renders) are produced for every group EXCEPT `fab-fast`:**
  - `all` — everything
  - `fab` — gerbers + drill + zip (+ 3D); no schematic needed
  - `fab-fast` — **gerbers/drill/zip ONLY, no STEP, no PNG renders** (fast path)
  - `production` — fab + CPL + BOM CSV (+ 3D); needs a schematic
  - `docs` — schematic PDF + interactive HTML BOM (+ 3D); needs a schematic
  - `models` — STEP + top/bottom PNG renders only

Schematic-less boards (e.g. `pulser_panel`) auto-fall-back to fabrication + 3D.

## How the two engines split the work

- **KiBot** (`jlcpcb.kibot.yaml`) produces gerbers/drill/zip, CPL, BOM, schematic
  PDF, iBOM, and the **STEP** (output `step`, type `export_3d`). Groups
  `fab`/`production`/`docs`/`models` map to KiBot groups of the same name.
- **kicad-cli** does the **top/bottom PNG renders** directly (`render_pngs` in
  build.sh). KiBot's `render_3d` is bypassed because it refuses the kicad-cli
  backend on KiCad < 10.0.5 and its headless-GUI fallback fails on KiCad 10.

## The 3D-always default + fast path (current behaviour)

Originally 3D only ran for `all`/`models`, so `build.sh mux production` produced
no `3D/` folder — that's why the mux was missing its top/bottom views. Now:

- build.sh folds the `step` KiBot target into `fab`/`production`/`docs`, and
  `render_pngs` runs unconditionally — **gated by `WITH_3D` (default 1)**.
- `fab-fast` sets `WITH_3D=0` and targets `fab` only → gerbers + zip in ~2 s,
  vs ~35 s when the two PNG renders run (~17 s each at 1600×1200, quality high).

To skip 3D on any build, use `fab-fast`. To force only-3D, use `models`.

## Environment / gotchas

- KiBot runs from a dedicated **Python 3.10 venv** at `hardware/.venv-kibot`
  (`--system-site-packages` so it can import KiCad's `pcbnew`). Auto-created on
  first run from `requirements-kibot.txt` (installed `--no-compile`; KiBot's
  macros break when byte-compiled). Not the repo `.venv`.
- 3D model libs: build.sh points `KICAD_3DMODELS_DIR` / `KICAD6_3DMODEL_DIR` at
  `/usr/share/kicad/3dmodels` (KiCad 10 no longer defines them).
- STEP export returns non-zero because a few component models are unavailable on
  this machine (SamacSys ICs under Windows-only paths, the VRML-only Pico model).
  build.sh uses KiBot `-D` (don't-stop) and still writes a valid STEP of the
  board + resolvable parts; the non-zero rc is reported as a warning only.
- **Side-effect-free**: build.sh snapshots the `.kicad_*` sources before running
  and restores them on exit (KiCad 10's kicad-cli silently migrates/rewrites
  older-format files just by opening them), and cleans KiBot's `kibot_*` strays.
- `build_<vendor>/` folders are build artefacts; `.claude/` is now gitignored
  and untracked (unrelated repo hygiene).

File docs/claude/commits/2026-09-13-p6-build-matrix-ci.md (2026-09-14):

# 2026-09-13 — P6: 6-variant build matrix + CI

Firmware **v0.1.9**. Branch `feature/unify-firmware-dsp`.

## What
- `build.sh` now builds **six** variants into `firmware/dist/`:
  `rp2040-{mux,nomux}`, `rp2350-{mux,nomux}` (stdio/non-DSP), and
  `rp2350-{mux,nomux}-dsp` (raw-TinyUSB DSP). Still copies the two mux non-DSP
  builds to `rp2040.uf2` / `rp2350.uf2`.
- DSP builds share one CMSIS-DSP clone via `-DFETCHCONTENT_BASE_DIR=firmware/.deps`
  (gitignored) so the second DSP build reuses the first's checkout.
- `.gitignore`: added `build2350-dsp*`, `.deps/`.
- CI (`.github/workflows/firmware.yml`): added an `actions/cache` step for
  `firmware/.deps` (key `cmsis-dsp-v1.17.0`). The build step already runs
  `./build.sh`, and the artifact upload + release `files: firmware/dist/*.uf2`
  automatically pick up all 6.

## Why
Expose every build combination as a downloadable artifact / release asset, and
keep CI (and repeated local builds) fast by not re-cloning CMSIS-DSP.

## Verification
`./build.sh` builds all 6 uf2 locally (first DSP build clones CMSIS-DSP into
`.deps`, second reuses it).

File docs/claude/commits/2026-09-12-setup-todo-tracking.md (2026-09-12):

# 2026-09-12 — Set up TODO/DONE tracking, retire QUESTIONS.md

## What
- Added `docs/claude/TODO.md` (open actions) and `docs/claude/DONE.md`
  (completed actions).
- Added `docs/claude/commits/` with a `README.md` describing the per-commit
  log convention (this folder).
- Transformed the 14 items in the repo-root `QUESTIONS.md` into actionable,
  tagged TODO entries ([claude]/[maintainer]/[mixed]) and **deleted**
  `QUESTIONS.md`.
- Noted the convention in `docs/claude/README.md`.

## Why
The user asked for a durable, cross-session task list and an audit trail of
commits. The old `QUESTIONS.md` was a flat list of open questions; folding it
into `TODO.md` makes each item an owned, checkable action.

## Notes / discoveries
- `QUESTIONS.md` Q1 referenced a repo-root `TODO.md` describing a DMA-timeout
  `sleep_us(1)` fix. **No such file exists** in the repo — `docs/claude/TODO.md`
  now carries the only surviving record of that proposed fix.

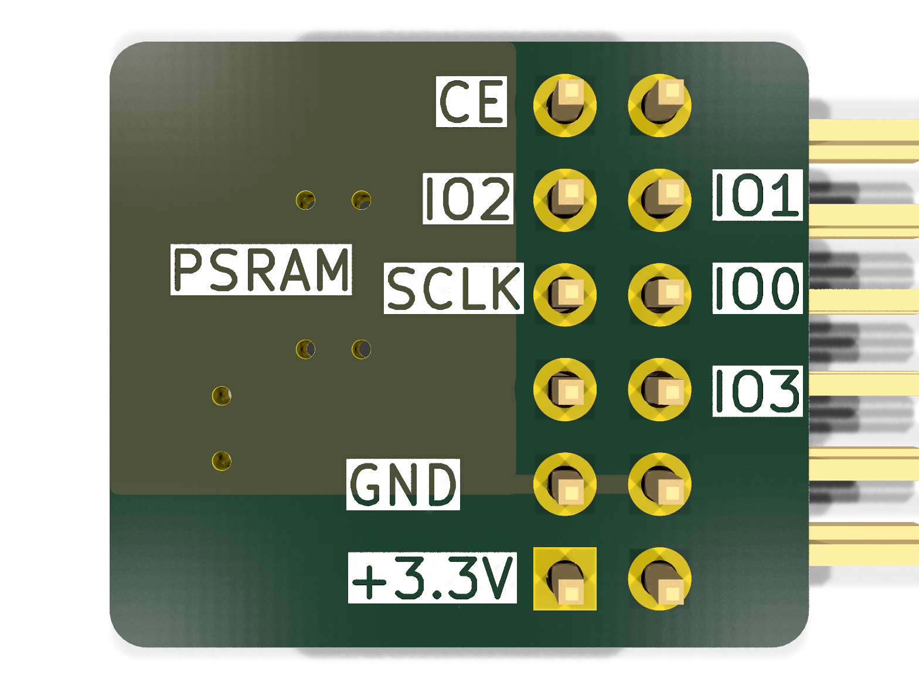
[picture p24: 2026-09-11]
hardware/psram/build_jlcpcb/3D/PMOD2PSRAM-3D-bottom.png

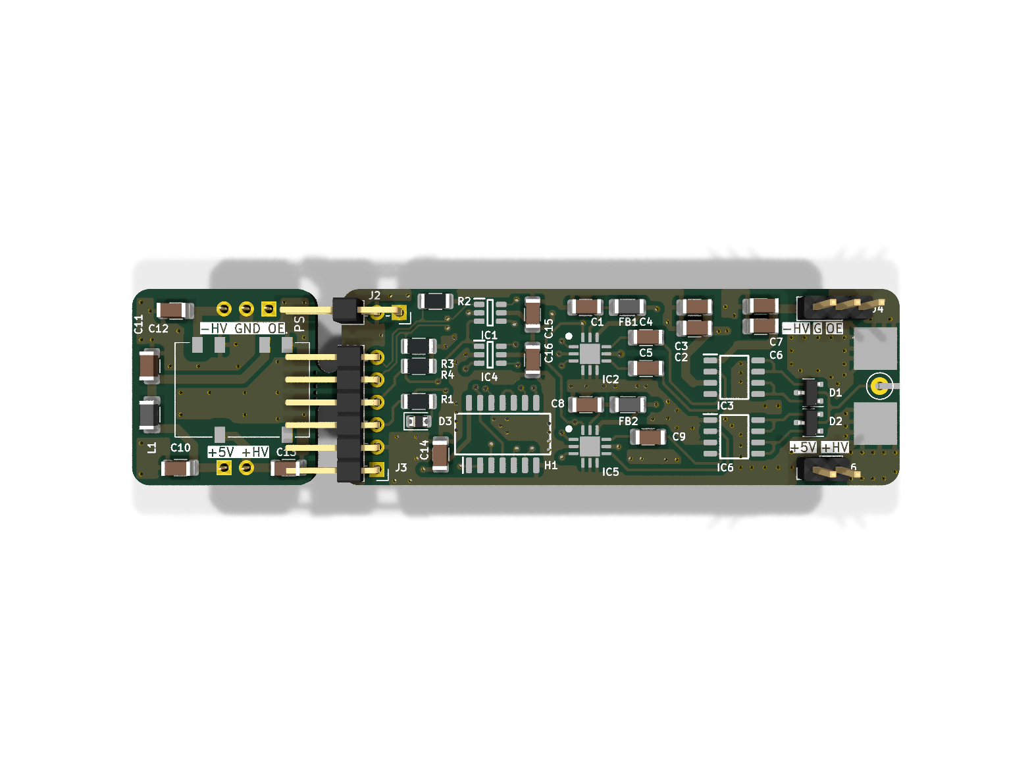
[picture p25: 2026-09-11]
hardware/pulser_panel/build_jlcpcb/3D/panel-3D-top.png

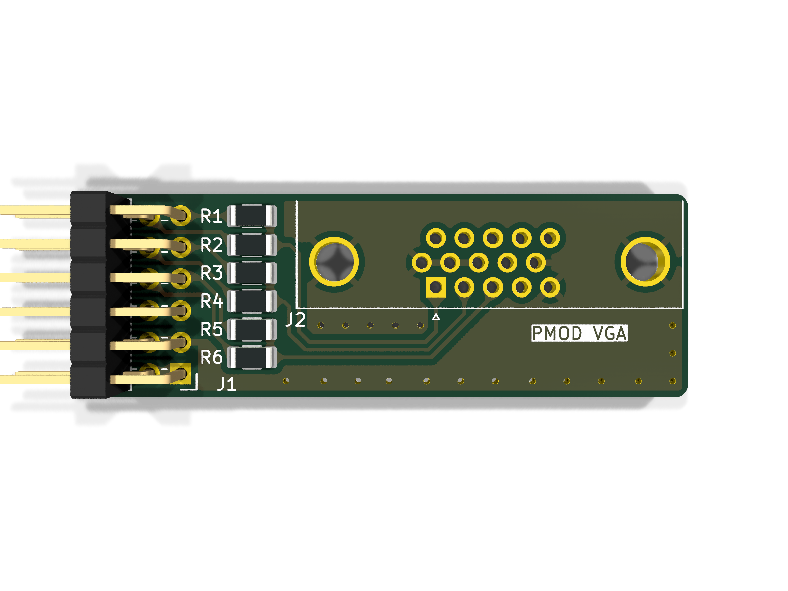
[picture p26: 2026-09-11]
hardware/vga/build_jlcpcb/3D/PMOD2VGA-3D-top.png

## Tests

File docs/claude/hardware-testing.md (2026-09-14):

# Hardware testing — working notes

How to flash and talk to a physically-connected pic0rick board from this machine,
and the verified flash/DFU iterate loop. Written 2026-09-13 against a connected
**RP2350A-with-wifi (Pico 2 W)** dev board.

## The connected device (2026-09-13)

- Board: RP2350A with wifi = **Pico 2 W**. We build/flash the **`pico2`** target
  (not `pico2_w`) — the firmware uses no wifi/CYW43, so it runs fine. **If wifi
  is ever used, build `pico2_w` instead.**
- USB IDs:
  - Running app firmware: `2e8a:0009` ("Raspberry Pi Pico"), a USB-CDC serial
    port at **`/dev/ttyACM0`** (115200 baud).
  - BOOTSEL / bootloader ("DFU"): `2e8a:000f` ("RP2350 Boot"), a mass-storage
    device that **auto-mounts at `/media/kelu/RP2350`**.

## Flashing (UF2 → mass storage)

Device must be in BOOTSEL first (see reboot-dfu below, or hold BOOTSEL on power-up).

```bash
cp firmware/dist/pic0rick-v<ver>-rp2350-mux.uf2 /media/kelu/RP2350/ && sync
```
The device reboots into the app automatically; the CDC port reappears at
`/dev/ttyACM0` within ~1–2 s.

## Talking to the REPL

The firmware blocks on `stdio_usb_connected()` at boot, so it only starts the
`run> ` REPL once a host **opens the port with DTR asserted** (pyserial does this
by default). Minimal check:

```python
import time, serial
s = serial.Serial("/dev/ttyACM0", 115200, timeout=0.3)
time.sleep(1.0); s.reset_input_buffer()
s.write(b"version\n"); time.sleep(1.0)
print(s.read(4096).decode("utf-8","replace"))
```
Serial access works from the normal user (member of `dialout`; node is
`crw-rw----+ root dialout /dev/ttyACM0`).

## The flash/DFU iterate loop (verified 2026-09-13)

`reboot-dfu` (added fw v0.1.2) closes the loop so no BOOTSEL button press is
needed between flashes:

1. `cp <uf2> /media/kelu/RP2350/ && sync` → runs, CDC at `/dev/ttyACM0`.
2. Test over serial.
3. Send `reboot-dfu\n` → device drops to BOOTSEL (`2e8a:000f`) in ~2 s; CDC
   disappears, MSD re-mounts at `/media/kelu/RP2350`.
4. Back to step 1.

`reboot-dfu` calls `reset_usb_boot(0, 0)` (`pico/bootrom.h`, links
`pico_bootrom`; the call does not return).

## Verified on hardware (2026-09-13, fw v0.1.2, pico2/RP2350)

- `version` returned: `board: pico2 (RP2350)`, `mux: enabled (MAX14866)`,
  `build: <hash>-dirty` (dirty = built from an uncommitted tree),
  `release: .../fw-v0.1.2`.
- `reboot-dfu` reliably re-entered BOOTSEL; reflashing from `/media/kelu/RP2350`
  restored the running firmware.

## DSP build (`-DDSP=ON`, RP2350) specifics

The DSP firmware (`main_dsp.c`) uses **raw TinyUSB** (SDK stdio off), but still
enumerates as a CDC serial port at `/dev/ttyACM0`. Differences from the stdio
REPL:
- Control replies are `OK …` / `ERR <code> …` lines; there is no `run>` prompt.
- Commands: `status`, `help`, `version`, `reboot-dfu`, `pulser arm|disarm`,
  `pulse config …`, `dac write <0..1023>`, `dsp scale|selftest`,
  `acq raw|envelope|alaw`, `stream start|stop`, `write/set/clear mux` (MUX
  builds), legacy `start acq` / `read`.
- Data is returned as 64-byte-header binary frames (raw=type1 uint16,
  envelope=type2 f32, alaw=type3 u8) — e.g. `acq raw` → `OK capture started …`
  then a 64-byte header + 8192-byte payload (8256 B total for 4096 samples).
- No text is emitted while a stream is in flight.
- Verified 2026-09-13 on the RP2350A: version/help/status + `acq raw` frame.

## Gotchas

- The `-dirty` in the `build:` line just means the uf2 was built before
  committing; commit then rebuild for a clean hash.
- After `reboot-dfu`, wait for the MSD auto-mount (a couple of seconds) before
  copying the next UF2.
- Only the running app exposes the CDC; in BOOTSEL there is no `/dev/ttyACM*`.

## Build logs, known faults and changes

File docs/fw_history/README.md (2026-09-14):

# fw_history — reference firmware baselines

A **maintainer-curated** archive of known-good firmware `.uf2` binaries, kept as
regression baselines: a place to grab a firmware that is *known* to behave a
certain way (e.g. produce echoes) and A/B it against a current build.

## Naming

`fw<A.B.C>-<board>-<options>.uf2`, e.g. `fw0.1.1-RP2350-muxenabled.uf2`.
Include the firmware version, the board, and the notable build options.

## Rule — only the maintainer adds `.uf2` here

**Claude must never add, copy, build into, or commit `.uf2` files in this
folder.** These baselines are curated by the maintainer (Luc) only; they are
deliberate references, not build output. Claude's builds belong in
`firmware/dist/` (gitignored) and in GitHub releases.

Claude *may* edit this README, reference these baselines, and **flash** them to a
board for diagnostics — just not add new ones.

## Current baselines

- `fw0.1.1-RP2350-muxenabled.uf2` — last firmware before the DSP unification;
  the **stdio / old `adc.pio` pulser**, confirmed to produce strong pulse-echo
  signals (see `python/example_simple.ipynb`). Used as the reference when
  diagnosing the post-unification "no echo" regression (fixed in fw v0.1.11 —
  a MUX/pulser PIO1 state-machine conflict).

## Related

- `python/example_simple.ipynb` — minimal connect + capture that shows the echo
  peaks (variance in samples 2000–3000 ≫ 6000–7000) with this baseline.
- `docs/dsp_test_guide.md`, `firmware/CHANGELOG.md`.

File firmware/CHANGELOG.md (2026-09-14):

# Changelog — pic0rick firmware

All notable changes to the firmware (`firmware/`). Versions follow the `A.B.C`
scheme in `version.yaml` (major.minor.patch); the patch is bumped on every
change to `firmware/` source. Newest first.

This file and `version.yaml` are the version record — editing them does not
itself trigger a version bump. Every firmware version bump must add an entry
here (see `docs/claude/README.md`).

## 0.1.11 — 2026-09-13
- **Fix MUX/pulser PIO1 state-machine conflict (no-echo on MUX builds):**
  `max14866_init` hardcoded PIO1 `sm0`, but the shared pulser
  (`u4rk_acquisition_init`) claims PIO1 `sm0`/`sm1` first — so the mux init
  clobbered the pulser drive SM and no transmit pulse fired (only digital
  crosstalk, no echo). `max14866_init` now claims an unused SM. Confirmed on
  hardware: nomux builds already echoed; this restores echoes on MUX builds.

## 0.1.10 — 2026-09-13
- **Pulser fix (echo regression):** fire the bipolar pulse (both polarities
  back-to-back) **then** damp, matching the original stdio firmware (v0.1.0).
  The shared `pulser.pio` path (from P4b) had inserted the PDAMP damp phase
  *between* the negative and positive drive, splitting the bipolar excitation —
  which produced only a weak transmit and no echo. Reordered in
  `hw/acquisition.c` `queue_pulse` (no PIO change).

## 0.1.9 — 2026-09-13
- `build.sh` builds all 6 variants (rp2040 mux/nomux, rp2350 mux/nomux, rp2350
  mux/nomux +DSP) into `dist/`, sharing one CMSIS-DSP clone (`firmware/.deps`).
- CI caches `firmware/.deps` and builds/releases all 6 uf2.

## 0.1.8 — 2026-09-13
- Unified hardware drivers: the stdio and DSP builds now share one acquisition +
  pulser + spi1 DAC in `firmware/hw/`.
- The stdio build's `start acq` / `write dac` / `read` use the shared drivers
  (raw 8000).
- Retired the old PIO pulser (`adc/`) and PIO DAC (`max/dac.c`).

## 0.1.7 — 2026-09-13
- Two-length acquisition: `read_raw` = 8000-sample raw ADC (no FFT),
  `read_fft` = 4096-sample Hilbert envelope. Sample count is per-capture and
  self-described by the frame header. (DSP build.)

## 0.1.6 — 2026-09-13
- First runnable DSP build (`-DDSP`, RP2350): raw-TinyUSB command loop
  (`main_dsp.c`) with the onboard-DSP commands plus `version`, `reboot-dfu`, and
  (with `-DMUX`) `write/set/clear mux`. Non-DSP stdio builds unchanged.

## 0.1.5 — 2026-09-13
- Landed the onboard-DSP modules under `firmware/dsp/` as the `p0rk_dsp` static
  library (compiled only when `-DDSP=ON`). Not yet wired into the command loop.

## 0.1.4 — 2026-09-13
- Added the `-DDSP` build-option scaffolding (RP2350/`pico2`-guarded) that
  fetches CMSIS-DSP; firmware sources wired in later. Default builds unchanged.

## 0.1.3 — 2026-09-13
- Build against Pico SDK 2.3.0 (was 2.2.0), preparing for the onboard-DSP
  unification (needs 2.3.0 + CMSIS-DSP).

## 0.1.2 — 2026-09-13
- Added the `reboot-dfu` CLI command: reboots into the USB bootloader (BOOTSEL)
  so a new UF2 can be flashed without pressing BOOTSEL.

## 0.1.1 — 2026-09-13
- `version` command now also reports board/chip, MUX state, the git build hash
  (with `-dirty`) and the GitHub release URL.
- CI release notes list both the firmware and python library versions.

## 0.1.0 — 2026-09-13
- First versioned firmware: added the `version` CLI command (reads
  `version.yaml`); the MAX14866 MUX board is now optional at compile time via
  `-DMUX`.

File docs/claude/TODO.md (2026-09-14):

# TODO — pic0rick

Open, actionable items for Claude Code and the maintainer. Completed items move
to `DONE.md`. Every commit that touches this repo also gets a log entry in
`docs/claude/commits/`.

Legend: **[claude]** doable by Claude from the code · **[maintainer]** needs a
hardware fact or product decision only Luc can supply · **[mixed]** Claude can
implement once a maintainer decision/measurement is provided.

Sourced from the former `QUESTIONS.md` (documentation review, 2026-09-12) plus
discoveries logged since.

---

## Firmware

- [ ] **[maintainer]** Confirm the DMA-timeout race fix is wanted: insert
  `sleep_us(1)` after `pio_sm_put_blocking(pio_adc, sm, SAMPLE_COUNT)` in
  `pulse_adc_trigger` (`firmware/adc/adc.c:131`) so the ADC SM reaches its
  `wait irq 0` state before the pulse fires. *Note: the `TODO.md` that the old
  QUESTIONS.md cited does not exist in the repo — this is the only surviving
  record of that fix.* (was Q1)
- [ ] **[maintainer]** RP2350 build status: is `build2350/` tested and confirmed
  working? Document any deltas from RP2040 (clock dividers, PIO programs, DMA
  channels). (was Q2)
- [ ] **[maintainer]** Document hardware-safe upper limits for `pon` / `poff` /
  `damp` (ns). Firmware accepts any `int`; the pulser board has real limits
  (inductor saturation, HV cap discharge). (was Q3)
- [ ] **[mixed]** `SAMPLE_COUNT` is hardcoded to 8000 in `firmware/adc/adc.h`.
  Decide whether to expose it as a serial command (needs a runtime-sized DMA
  buffer) or keep it a compile-time constant; document the choice. (was Q4)

## Hardware

- [ ] **[maintainer]** Characterise HV rail voltage spread across production
  boards (IAS0105D24 spec ±24V; no on-board monitoring). (was Q5)
- [ ] **[maintainer]** Document the `OE` signal on J5 pin 3: active-high/low, and
  whether it is RP2040-driven or tied static. (was Q6)
- [ ] **[maintainer]** Reconcile production PCB vs. `main`-branch KiCad. Production
  appears to be commit `bab83371f452f650acd79c82d3ccac702bd4d4ba`; either note
  the production tag in the README or update the main-branch files. (was Q7)
- [ ] **[maintainer]** Locate/add the MUX board KiCad files. `write/set/clear mux`
  (MAX14866) are in firmware and the README lists a MUX design entry, but there
  is no `hardware/mux/` directory. (was Q8)

## Python library

- [ ] **[mixed]** Publish a `dac_to_db(n)` helper and label plots in dB. Needs
  the board VREF for the MCP4812 (AD8331 VGAIN: 0V→7.5dB, 1V→55.5dB). (was Q9)
- [ ] **[maintainer]** Verify `Fech = 60e6` (`device.py:64`) against a frequency
  counter or known-thickness calibration; add a trim/calibration path if it
  differs. (was Q10)
- [ ] **[maintainer]** Decide `requirements.txt` scope: replace the 122-package
  `pip freeze` with `requirements-minimal.txt`, or keep both (dev freeze + minimal
  runtime). (was Q11)

## Documentation

- [ ] **[maintainer]** Write step-by-step assembly instructions for the 3-board
  stack (main + pulser + HV), with reference-designator callouts on the
  `docs/images/` photos. (was Q12)
- [ ] **[maintainer]** Clarify status of the `VGA` proof-of-concept branch — flag
  as experimental/archived in the README if not maintained. (was Q13)
- [ ] **[maintainer]** Document tested transducer frequencies/types and whether
  immersion probes are supported (any hardware changes needed). (was Q14)

## Discoveries (logged by Claude)

- [x] **[claude]** DSP **test guide** (`docs/dsp_test_guide.md`) and `python/`
  example (`python/example_dsp.py`) rewritten against the new API and
  hardware-tested (2026-09-13). *(A notebook version could still be added if the
  maintainer prefers one over the script.)*
- [ ] **[claude]** Optional: port the old capture tool's CLI (self-test
  validation, `save_frames`) onto `pic0rick.dsp` if a standalone DSP capture CLI
  is wanted (2026-09-13).

- [ ] **[mixed]** MUX not wired into the high-level acquisition flow.
  `device.py` now exposes `write_mux` / `set_mux` / `clear_mux`, but
  `ndt_acquisition.py` (`UltrasonicAcquisition`) never selects a mux channel.
  For multi-element / array probing, integrate mux selection into the
  acquisition sequence. Needs a decision on the intended channel-map semantics
  (found 2026-09-12 during firmware↔Python parity check).
- [ ] **[maintainer]** Document the MAX14866 mux bit-map: which bits in the
  16-bit `write mux` word map to which physical switch/channel. Needed before
  `write_mux` can be used meaningfully from Python (found 2026-09-12).
- [ ] **[maintainer]** Release cadence decision: CI cuts a release only when
  `fw-v<version>` doesn't already exist, so a main push that doesn't bump the
  firmware patch yields artifacts but no new release. Confirm this is desired, or
  ask for per-commit releases (would need a unique tag e.g. `+<short-sha>`)
  (found 2026-09-13).
- [ ] **[maintainer]** First run of `.github/workflows/firmware.yml` needs
  `Settings → Actions → Workflow permissions = Read and write` (or the release
  step can't create tags/releases despite `permissions: contents: write`)
  (found 2026-09-13).
- [ ] **[claude]** The committed `firmware/rp2040.uf2` / `rp2350.uf2` are the
  mux builds refreshed at v0.1.0. Decide whether to keep binaries in git at all
  now that CI publishes releases, or drop them and point users to releases
  (found 2026-09-13).

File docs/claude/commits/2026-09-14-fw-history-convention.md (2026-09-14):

# 2026-09-14 — docs/fw_history convention

Docs only. Branch `feature/unify-firmware-dsp`.

## What
- Added `docs/fw_history/README.md` documenting the reference-baseline archive:
  naming (`fw<A.B.C>-<board>-<options>.uf2`), purpose (regression baselines), the
  current `fw0.1.1-RP2350-muxenabled.uf2` entry, and links to
  `python/example_simple.ipynb`.
- **Rule:** only the maintainer adds `.uf2` to `docs/fw_history/`. Claude must
  never add/copy/build/commit a `.uf2` there (may edit the README and flash the
  baselines for diagnostics). Recorded in `docs/claude/README.md` and memory
  (`fw-history-maintainer-only`).

## Note
The baseline `.uf2` and `python/example_simple.ipynb` themselves were committed
by the maintainer (commit "aing luc's tests"), not here.

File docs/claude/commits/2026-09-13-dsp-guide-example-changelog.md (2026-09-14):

# 2026-09-13 — DSP test guide + example, firmware CHANGELOG + rule

Python library **v0.1.4**. Branch `feature/unify-firmware-dsp`.

## What
- **`docs/dsp_test_guide.md`** — new: build/flash/serial/Python walkthrough of
  the `-DDSP` firmware against the new API (`read_raw`/`read_fft`, `pic0rick.dsp`,
  `Pic0rick.status/read_fft/read_raw/capture`), replacing the dropped
  onboard_dsp `test_guide.md`/notebook.
- **`python/example_dsp.py`** — new: end-to-end example (status → read_raw →
  read_fft → pulsed read_fft; optional `--save` .npy / `--plot` PNG).
- **`firmware/CHANGELOG.md`** — new: per-version history (0.1.0 → 0.1.9).
- **Rule added:** every firmware version bump must add a `firmware/CHANGELOG.md`
  entry; `version.yaml` + `CHANGELOG.md` are the version record and editing only
  them does not trigger a bump. Recorded in `docs/claude/README.md` and the
  `versioning-rule` memory.

## Verified on hardware (RP2350A, DSP v0.1.9 build)
`python example_dsp.py --save /tmp/dsp_out`:
- status → firmware 0.1.9, RP2350A, backend f32-rfft-hilbert.
- read_raw → 8000 uint16 (min/mean/max 138/342/480).
- read_fft → 4096 float32 envelope, peak 113 (idle).
- read_fft with pulser armed → peak 388.7 (pulser path confirmed).
- raw.npy / envelope.npy saved.

## Note
Creating `firmware/CHANGELOG.md` did not bump the firmware version (it is version
bookkeeping). `example_dsp.py` is a python/ addition → python v0.1.4.

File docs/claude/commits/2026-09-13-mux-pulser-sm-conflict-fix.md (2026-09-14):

# 2026-09-13 — Fix MUX/pulser PIO1 SM conflict (the real no-echo cause)

Firmware **v0.1.11**. Branch `feature/unify-firmware-dsp`.

## The real root cause
Echoes worked on stdio v0.1.0 but not after unification. It was **not** OE, and
not (only) the damp ordering (v0.1.10). It was a **PIO1 state-machine collision**:

- `u4rk_acquisition_init()` (shared pulser) claims PIO1 `sm0` (pulser drive) and
  `sm1` (gate) via `pio_claim_unused_sm`.
- `max14866_init()` then **hardcoded `sm4 = 0`** and reconfigured PIO1 `sm0` for
  the mux SPI — clobbering the pulser's drive SM. So on **MUX builds** the P+/P-
  drive never ran: only digital crosstalk reached the ADC, no real HV pulse, no
  echo.

In v0.1.0/v0.1.1 there was no clash (old pulser on PIO0, mux on PIO1). The
unification moved the pulser to PIO1, creating the conflict.

## Fix
`max14866_init()` now `pio_claim_unused_sm(pio1, true)` instead of hardcoding
`sm0` (one line). Applies to both stdio and DSP mux builds.

## Verified on hardware (RP2350A, user's piezo)
Using the baseline method `pulse_adc_trigger(200,200,2000)` + `read`, measuring
`var[2000:3000]` (echo region) vs `var[6000:7000]` (quiet):

| build | var[2000:3000] | echoes |
|---|---|---|
| v0.1.10 mux (buggy) | ~0.4 | none |
| v0.1.10 **nomux** (isolation test) | 1442 | yes |
| **v0.1.11 mux (fixed)** | 1454 → **51,563** at gain 300 | yes |
| v0.1.1 baseline (reference) | 60,111 | yes |

Echo structure (main bang + 2–2.5k, 4.5–5k, 7k) matches the v0.1.1 baseline; at
gain 600+ the echo saturates. Confirmed the amplitude scales with the DAC.

## Notes
- The v0.1.10 damp-reorder (bipolar pulse then damp) is also correct and kept.
- This was found by predicting nomux would work (no mux ⇒ no SM clash) and
  testing it — it did, isolating the conflict.

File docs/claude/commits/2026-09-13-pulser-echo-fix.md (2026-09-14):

# 2026-09-13 — Pulser echo regression fix

Firmware **v0.1.10**. Branch `feature/unify-firmware-dsp`.

## Symptom
User: echoes worked on stdio **v0.1.0** but not after the unification (piezo
connected, no echo). Suspected the OE pin.

## Root cause
Not OE. OE polarity is correct (active-high; the pulser board AND-gates the drive
with OE via a `TC74VHC08`, and the firmware drives OE high through the transmit).
The regression was the **pulse waveform structure**, introduced in P4b when the
stdio build adopted the shared `pulser.pio`:
- v0.1.0 (`adc.pio`): bipolar pulse `P+`→`P-` back-to-back, **then** PDAMP damp.
- shared pulser: negative → **PDAMP damp** → positive (damp *between* the
  polarities). With the default 6 µs damp this splits the bipolar excitation into
  two weak, far-apart spikes → poor transmit, no echo.

## Fix
Reordered `hw/acquisition.c` `queue_pulse` so the two drive polarities fire
back-to-back and the PDAMP damp phase comes **last** (matching v0.1.0 and
standard pulser practice). No PIO change; affects both the stdio and DSP builds
(they share `firmware/hw`).

## Hardware evidence (RP2350A, v0.1.10 DSP)
- Before, a tight pulse gave a strong bang while the gapped default was weak.
- After the fix, the armed transmit is strong and consistent: ~200 counts at
  sample ~31 across shots, vs ~30 disarmed.
- **Echo-vs-target not confirmable on the bench** (no reflector/target here) —
  the user should verify with their piezo + a reflector.

## Notes
- Default pulse order is `neg-first`; v0.1.0 was effectively `pos-first`. Order
  only inverts the bipolar waveform, so it should not affect echo presence, but
  can be matched with `pulse config ... pos-first` if desired.
- First fix logged under the new CHANGELOG rule → `firmware/CHANGELOG.md` 0.1.10.

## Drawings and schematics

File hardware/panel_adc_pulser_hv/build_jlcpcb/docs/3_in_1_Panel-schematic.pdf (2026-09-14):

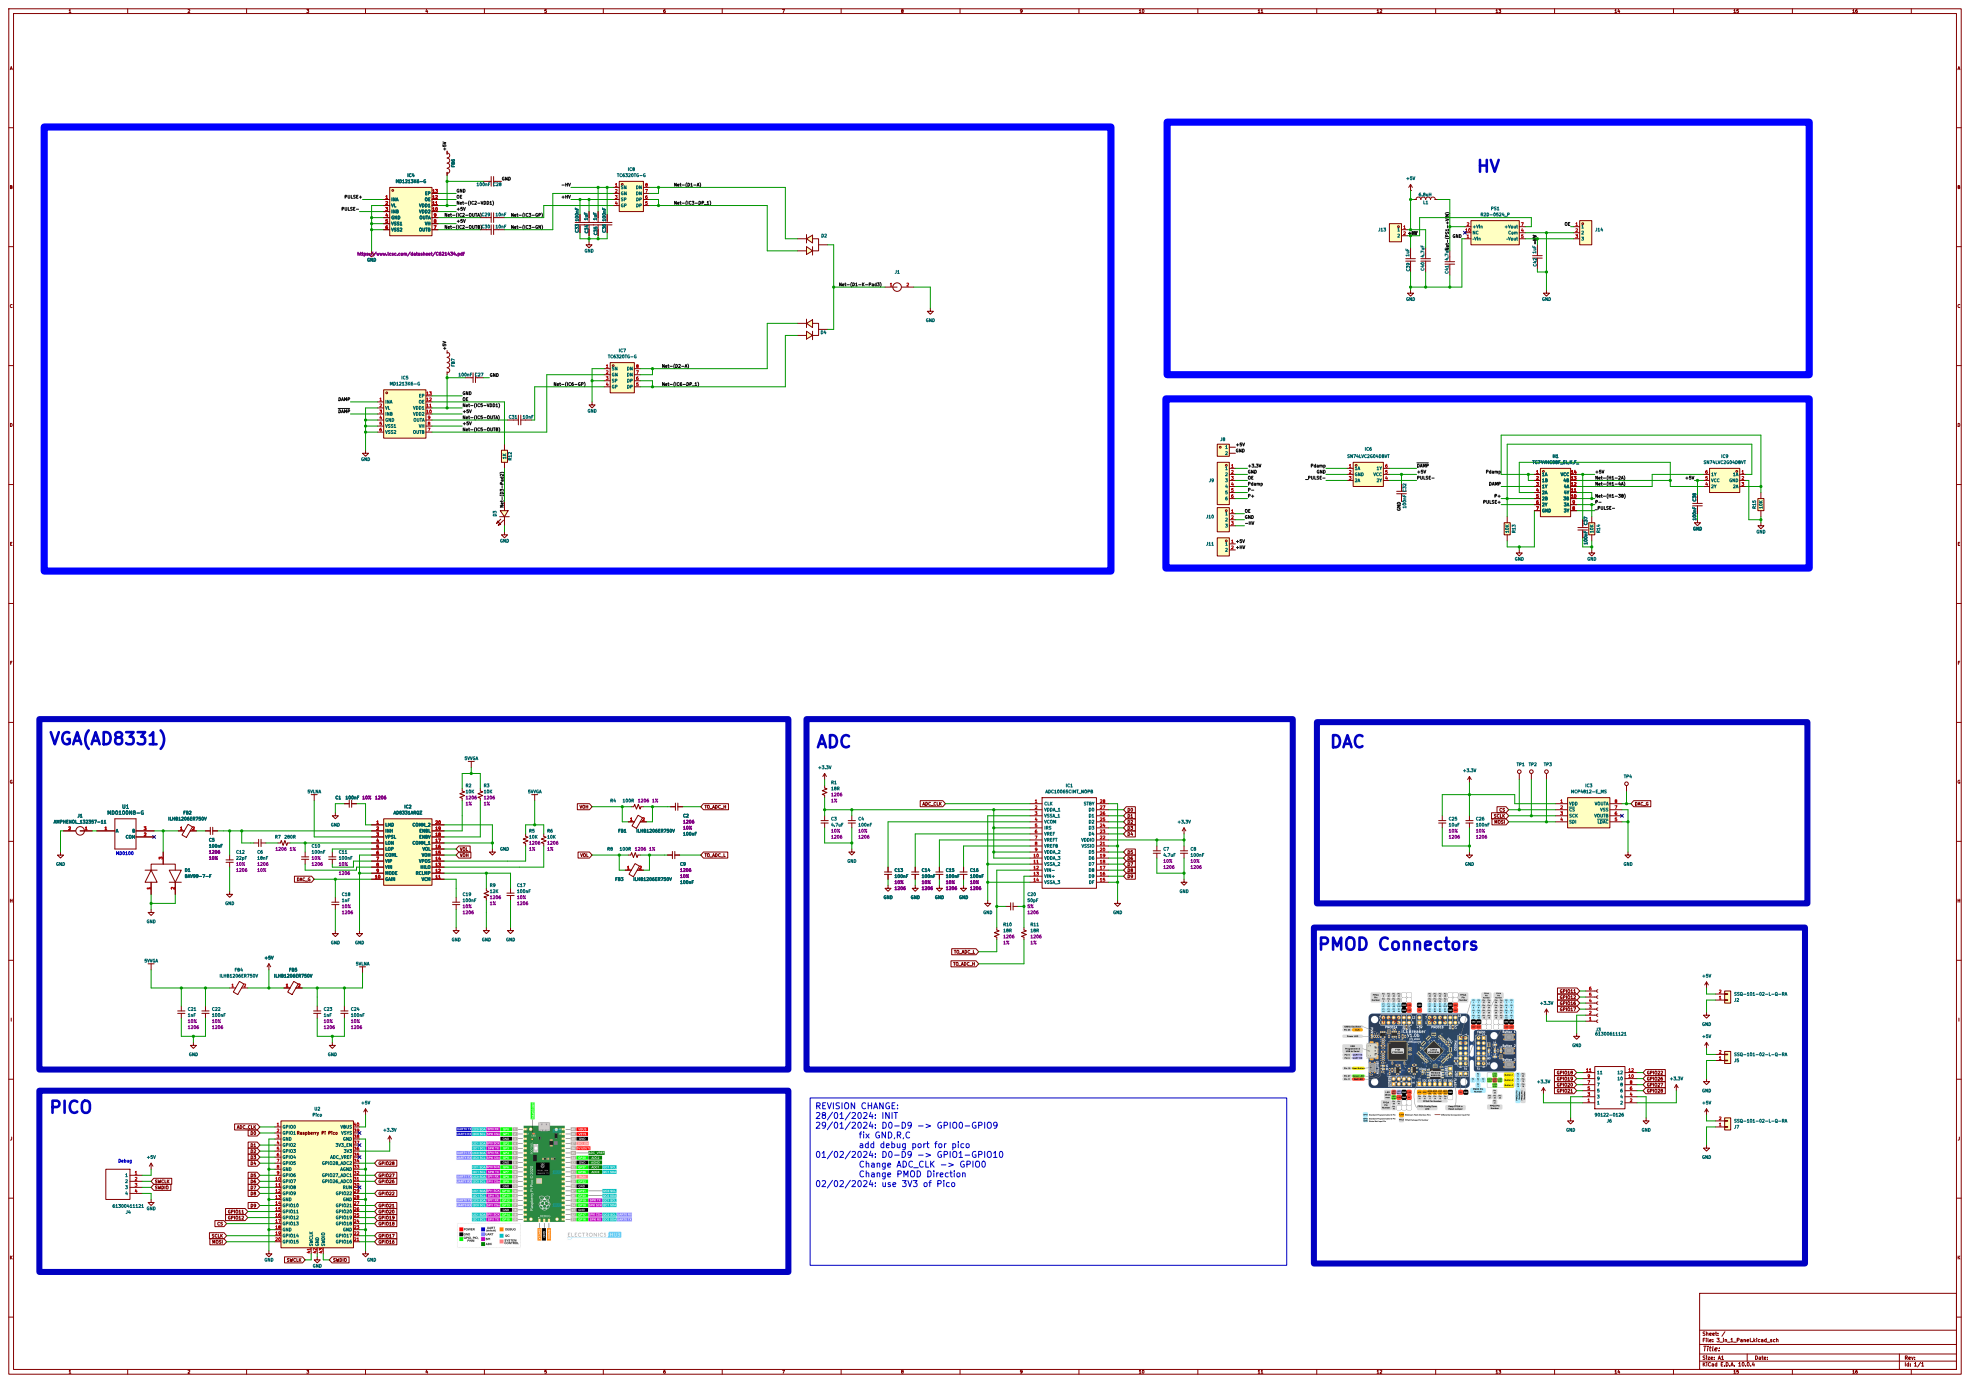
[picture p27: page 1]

GND OE GND Net-(IC5-OUTA) OENet-(IC5-VDD1)

https://www.lcsc.com/datasheet/C621434.pdf

VREFT 7
8 | 21

fix GND,R,C
add debug port for pico

Size: A1 | Rev:
KiCad E.D.A. 10.0.4 | Id: 1/1

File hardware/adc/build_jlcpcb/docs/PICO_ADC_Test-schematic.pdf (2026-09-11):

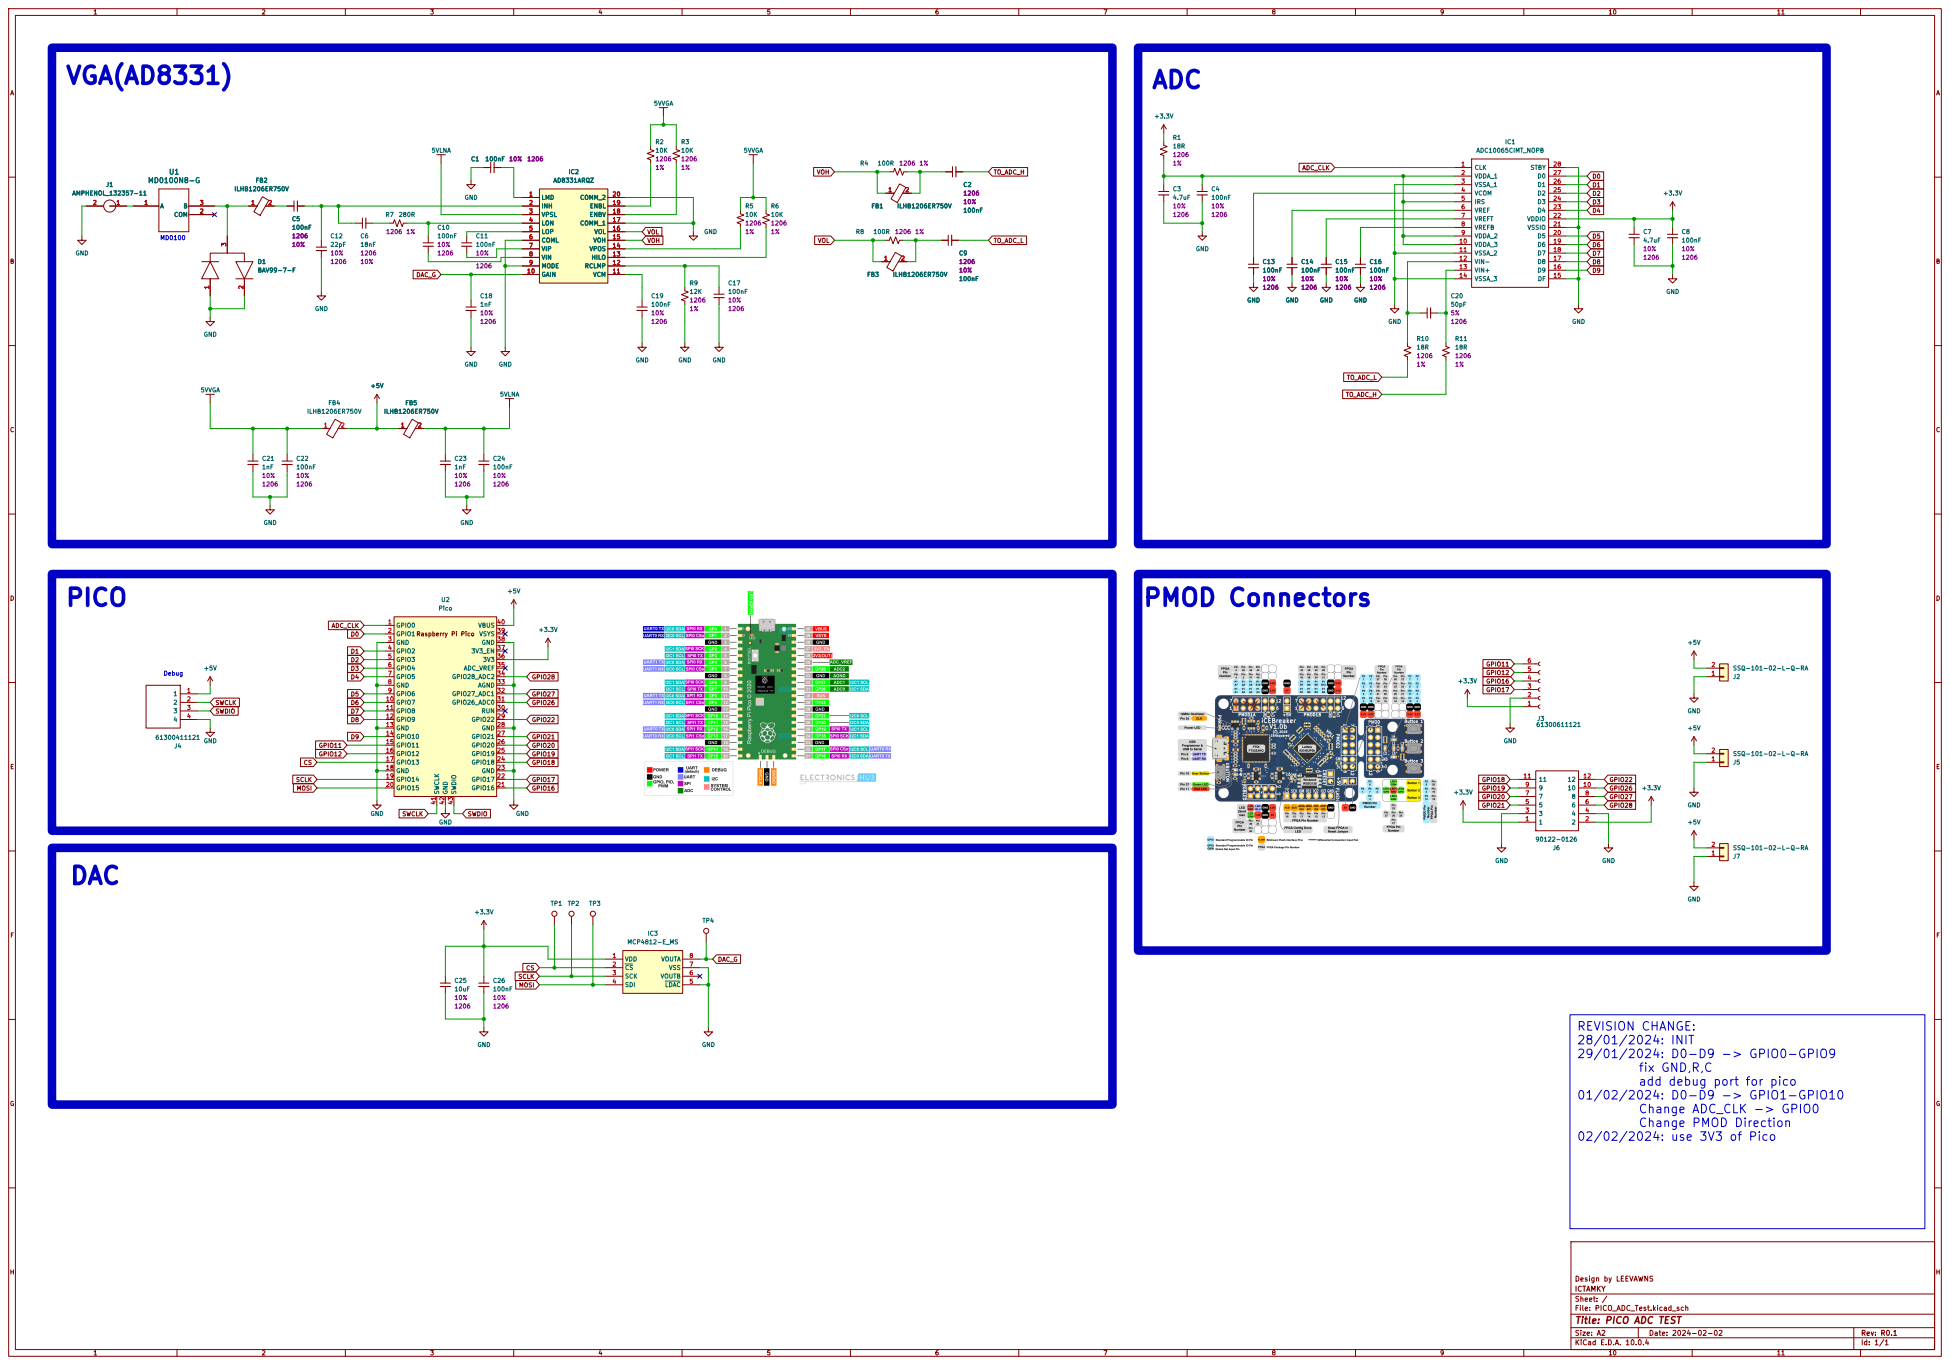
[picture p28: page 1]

fix GND,R,C
add debug port for pico

Design by LEEVAWNS
ICTAMKY
Sheet: /
File: PICO_ADC_Test.kicad_sch
Title: PICO ADC TEST

Size: A2 | Rev: R0.1
KiCad E.D.A. 10.0.4 | Id: 1/1

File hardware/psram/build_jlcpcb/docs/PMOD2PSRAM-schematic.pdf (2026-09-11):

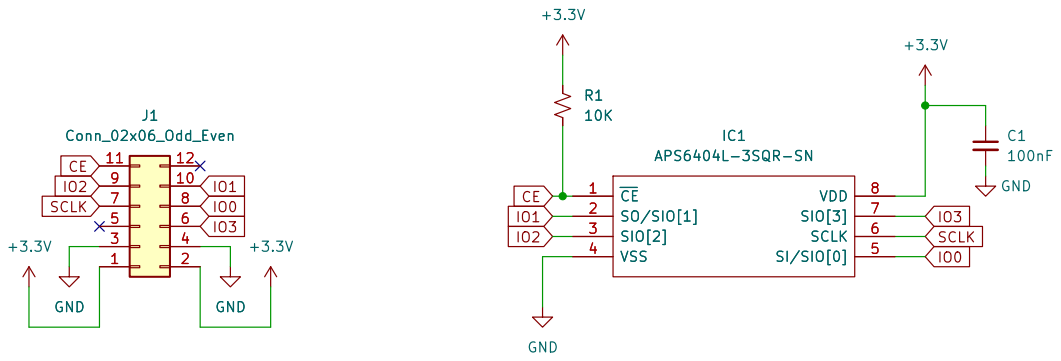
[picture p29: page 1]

https://un0rick.cc
Sheet: /
File: PMOD2PSRAM.kicad_sch
Title: PSRAM PMOD for pic0rick

Size: A4 | Rev: 1
KiCad E.D.A. 10.0.4 | Id: 1/1

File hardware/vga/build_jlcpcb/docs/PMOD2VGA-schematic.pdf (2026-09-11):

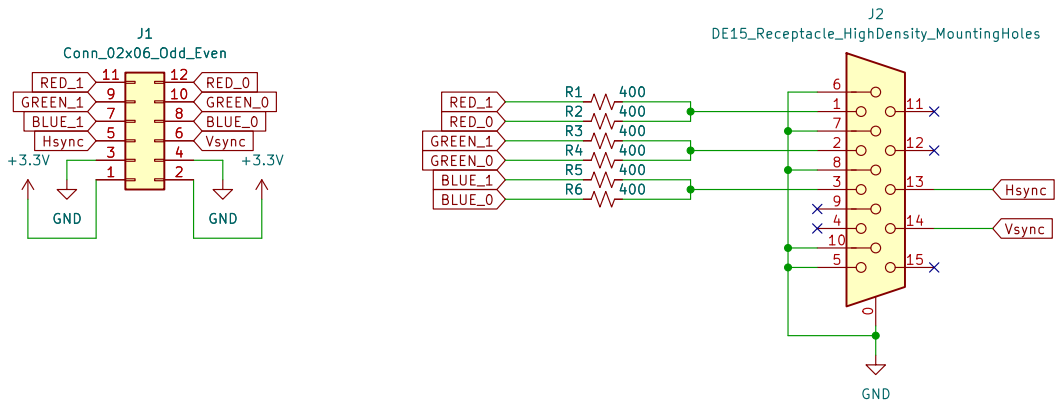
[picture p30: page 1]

https://un0rick.cc
Sheet: /
File: PMOD2VGA.kicad_sch
Title: PMOD for VGA for the pic0rick

Size: A4 | Rev: v1.0
KiCad E.D.A. 10.0.4 | Id: 1/1

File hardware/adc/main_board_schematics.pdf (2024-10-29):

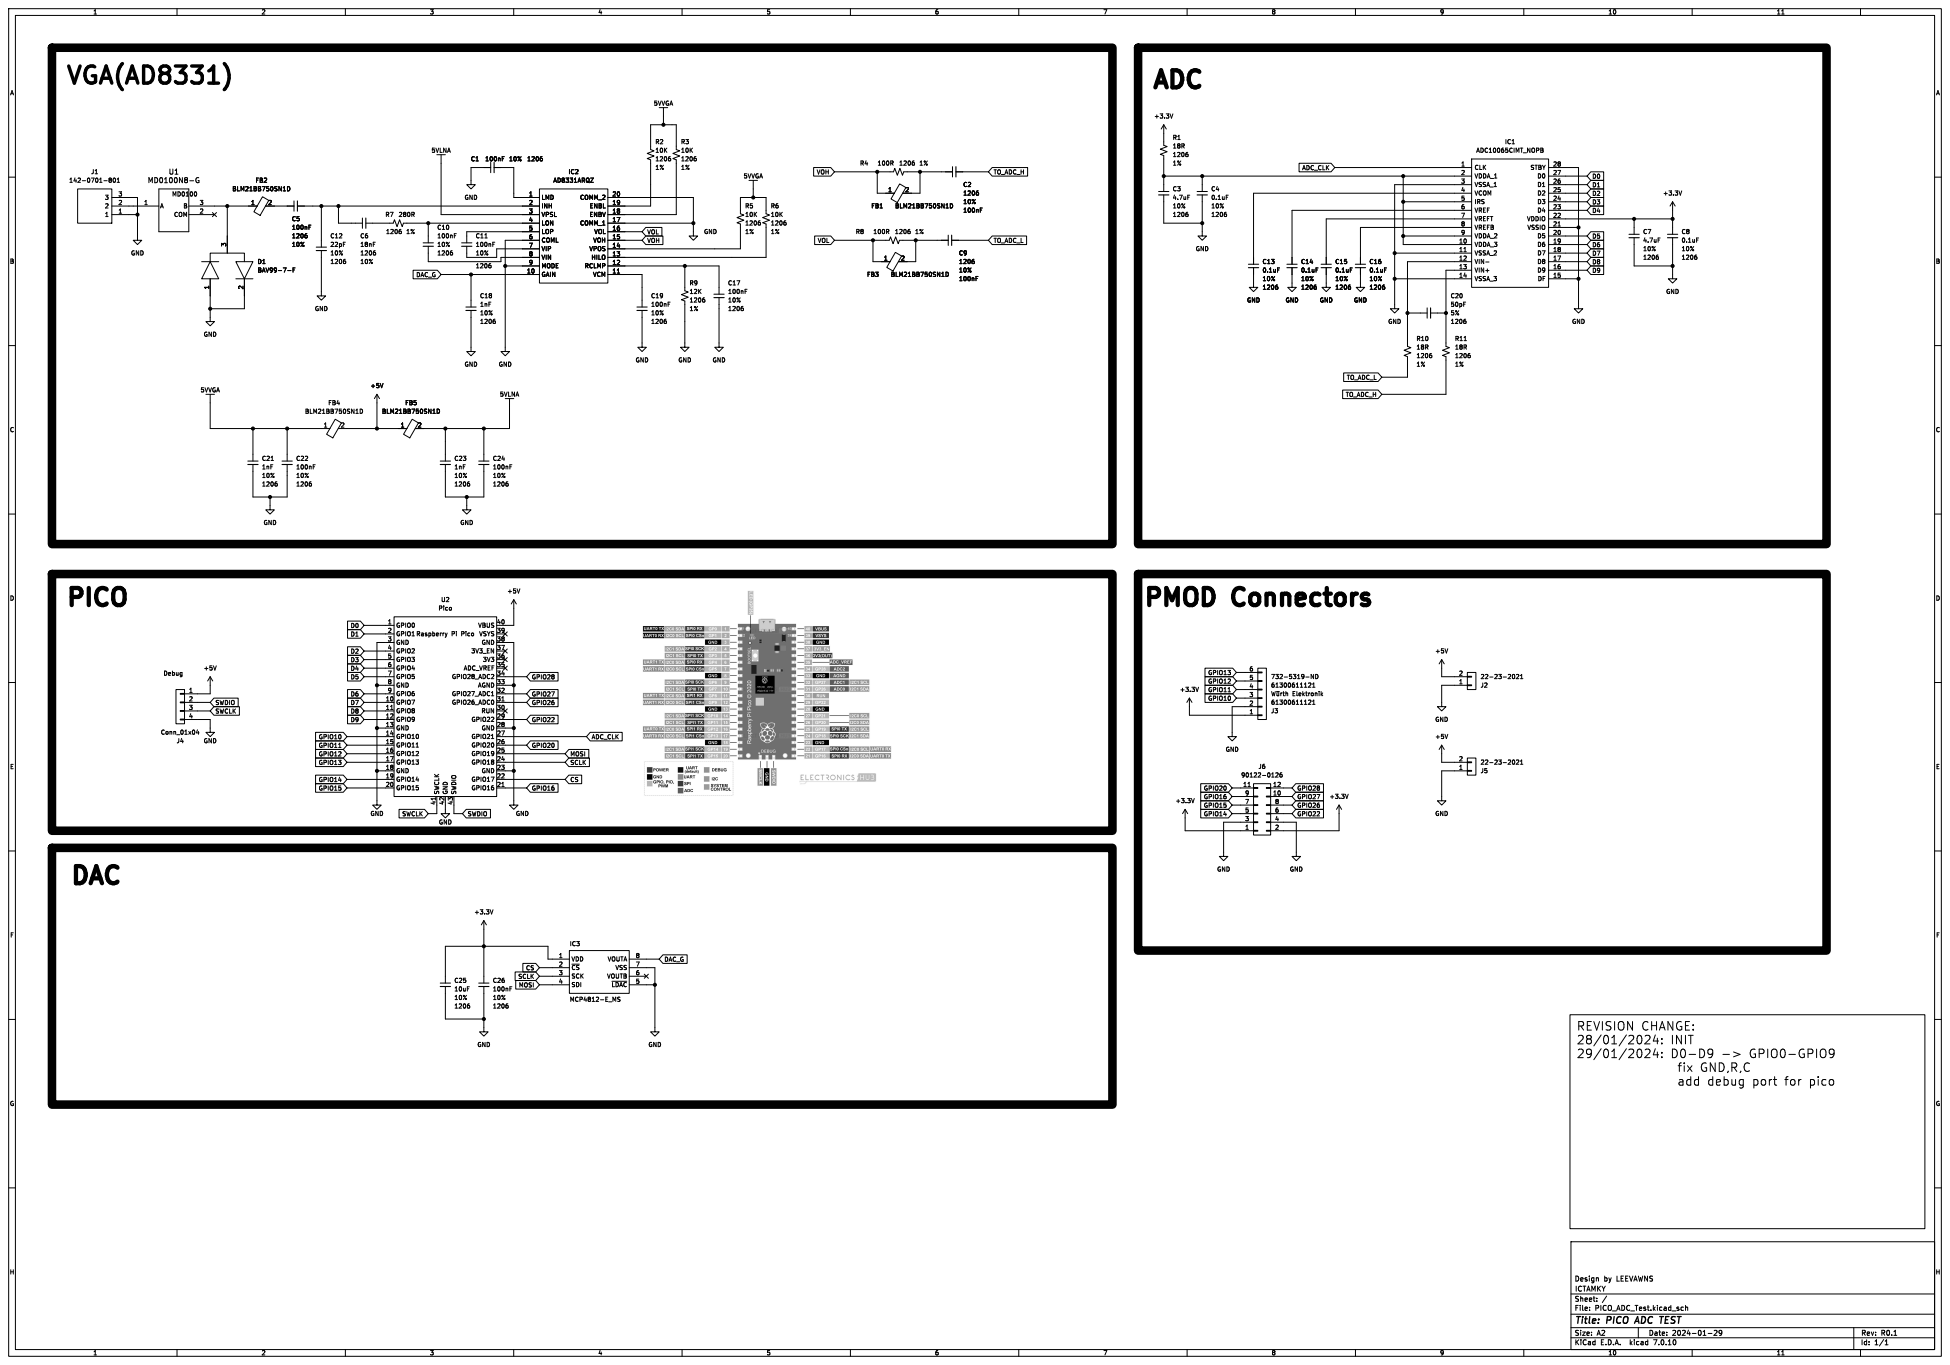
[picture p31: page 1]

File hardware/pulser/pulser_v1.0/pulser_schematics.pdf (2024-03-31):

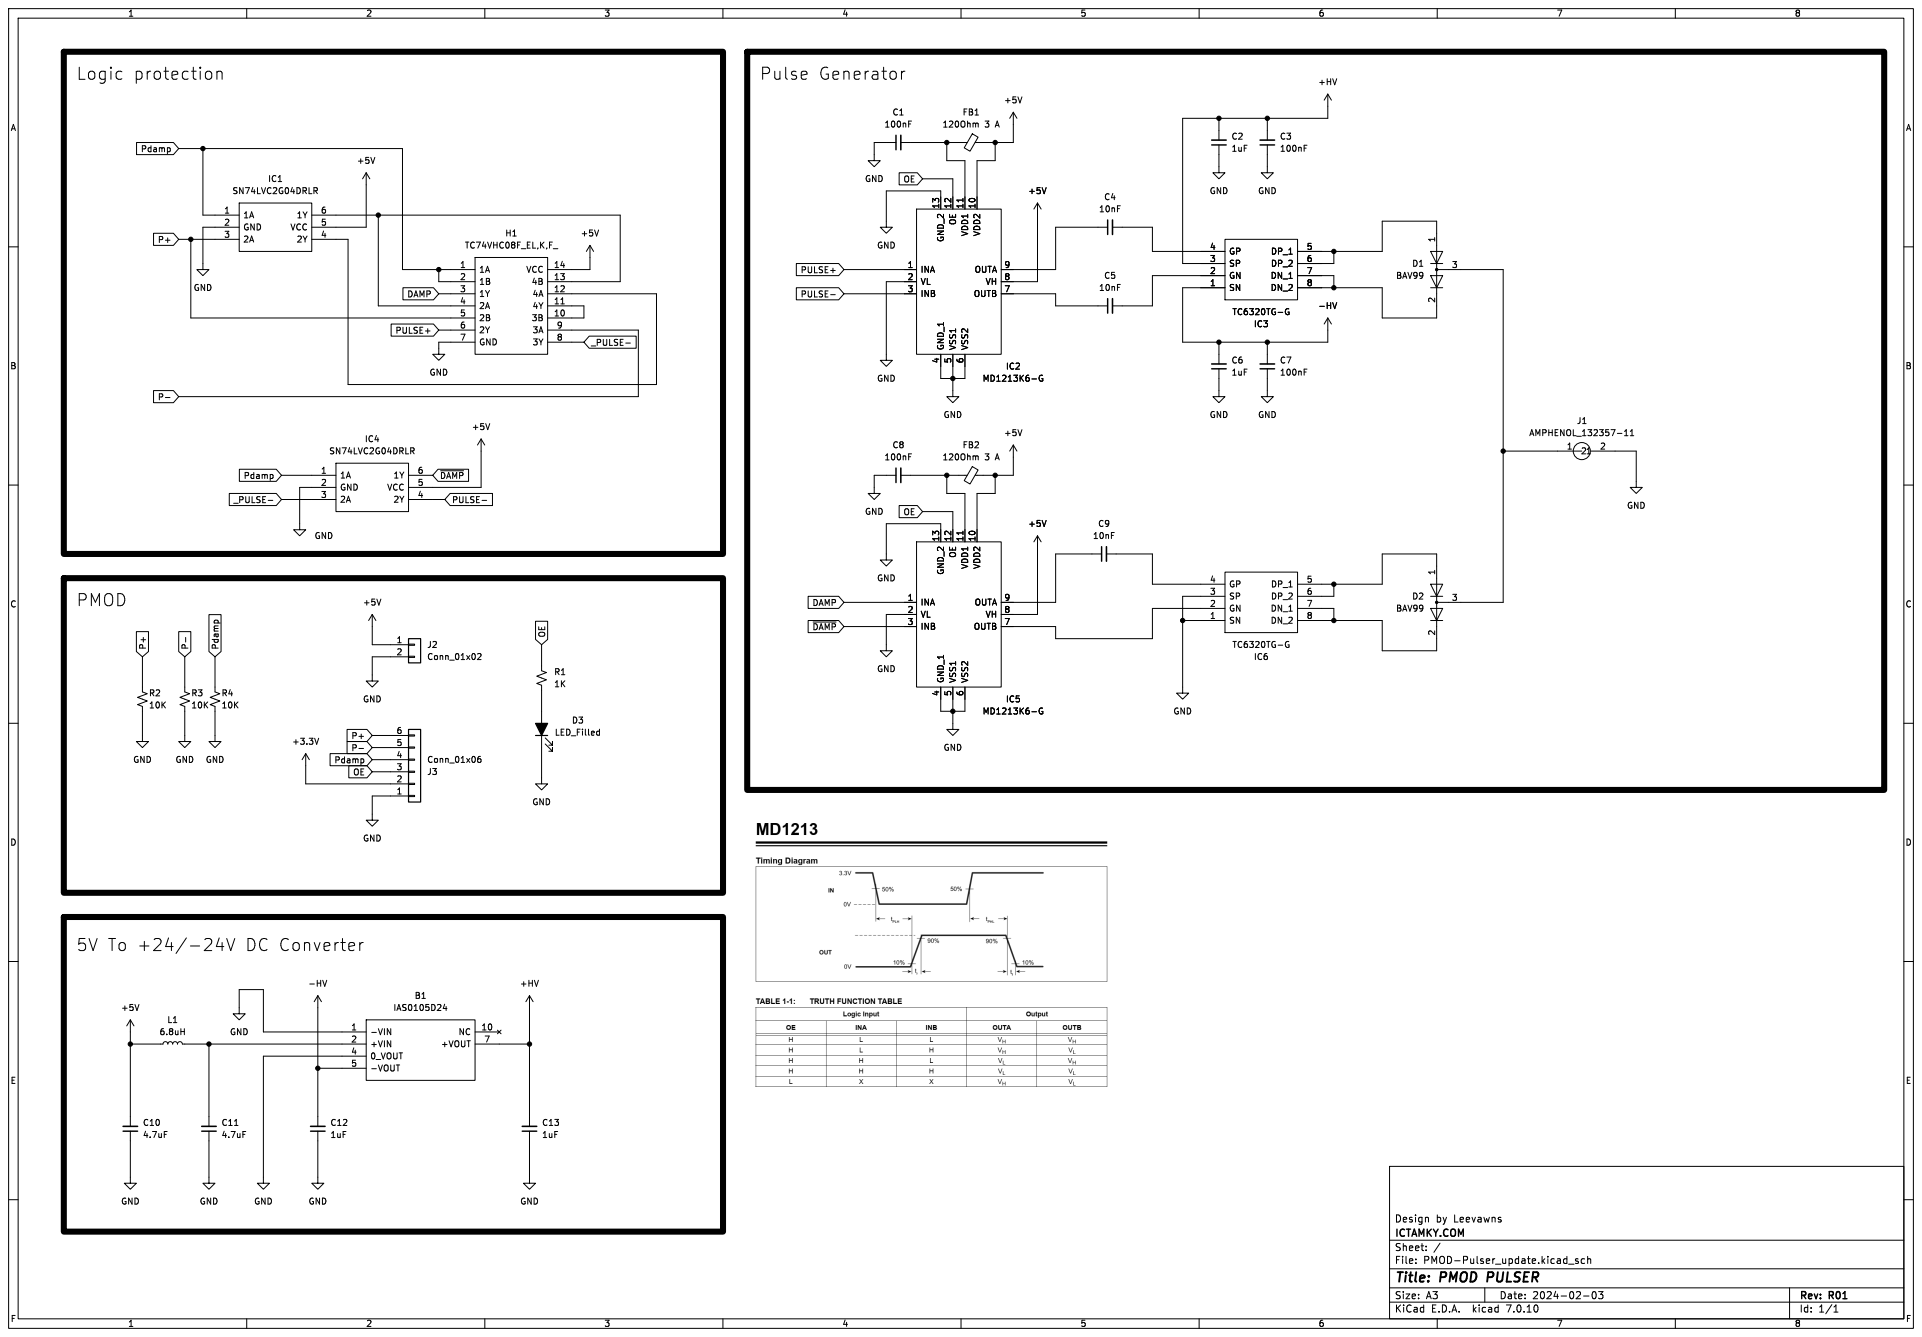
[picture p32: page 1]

ICTAMKY.COM
Id: 1/1 Title: PMOD PULSER

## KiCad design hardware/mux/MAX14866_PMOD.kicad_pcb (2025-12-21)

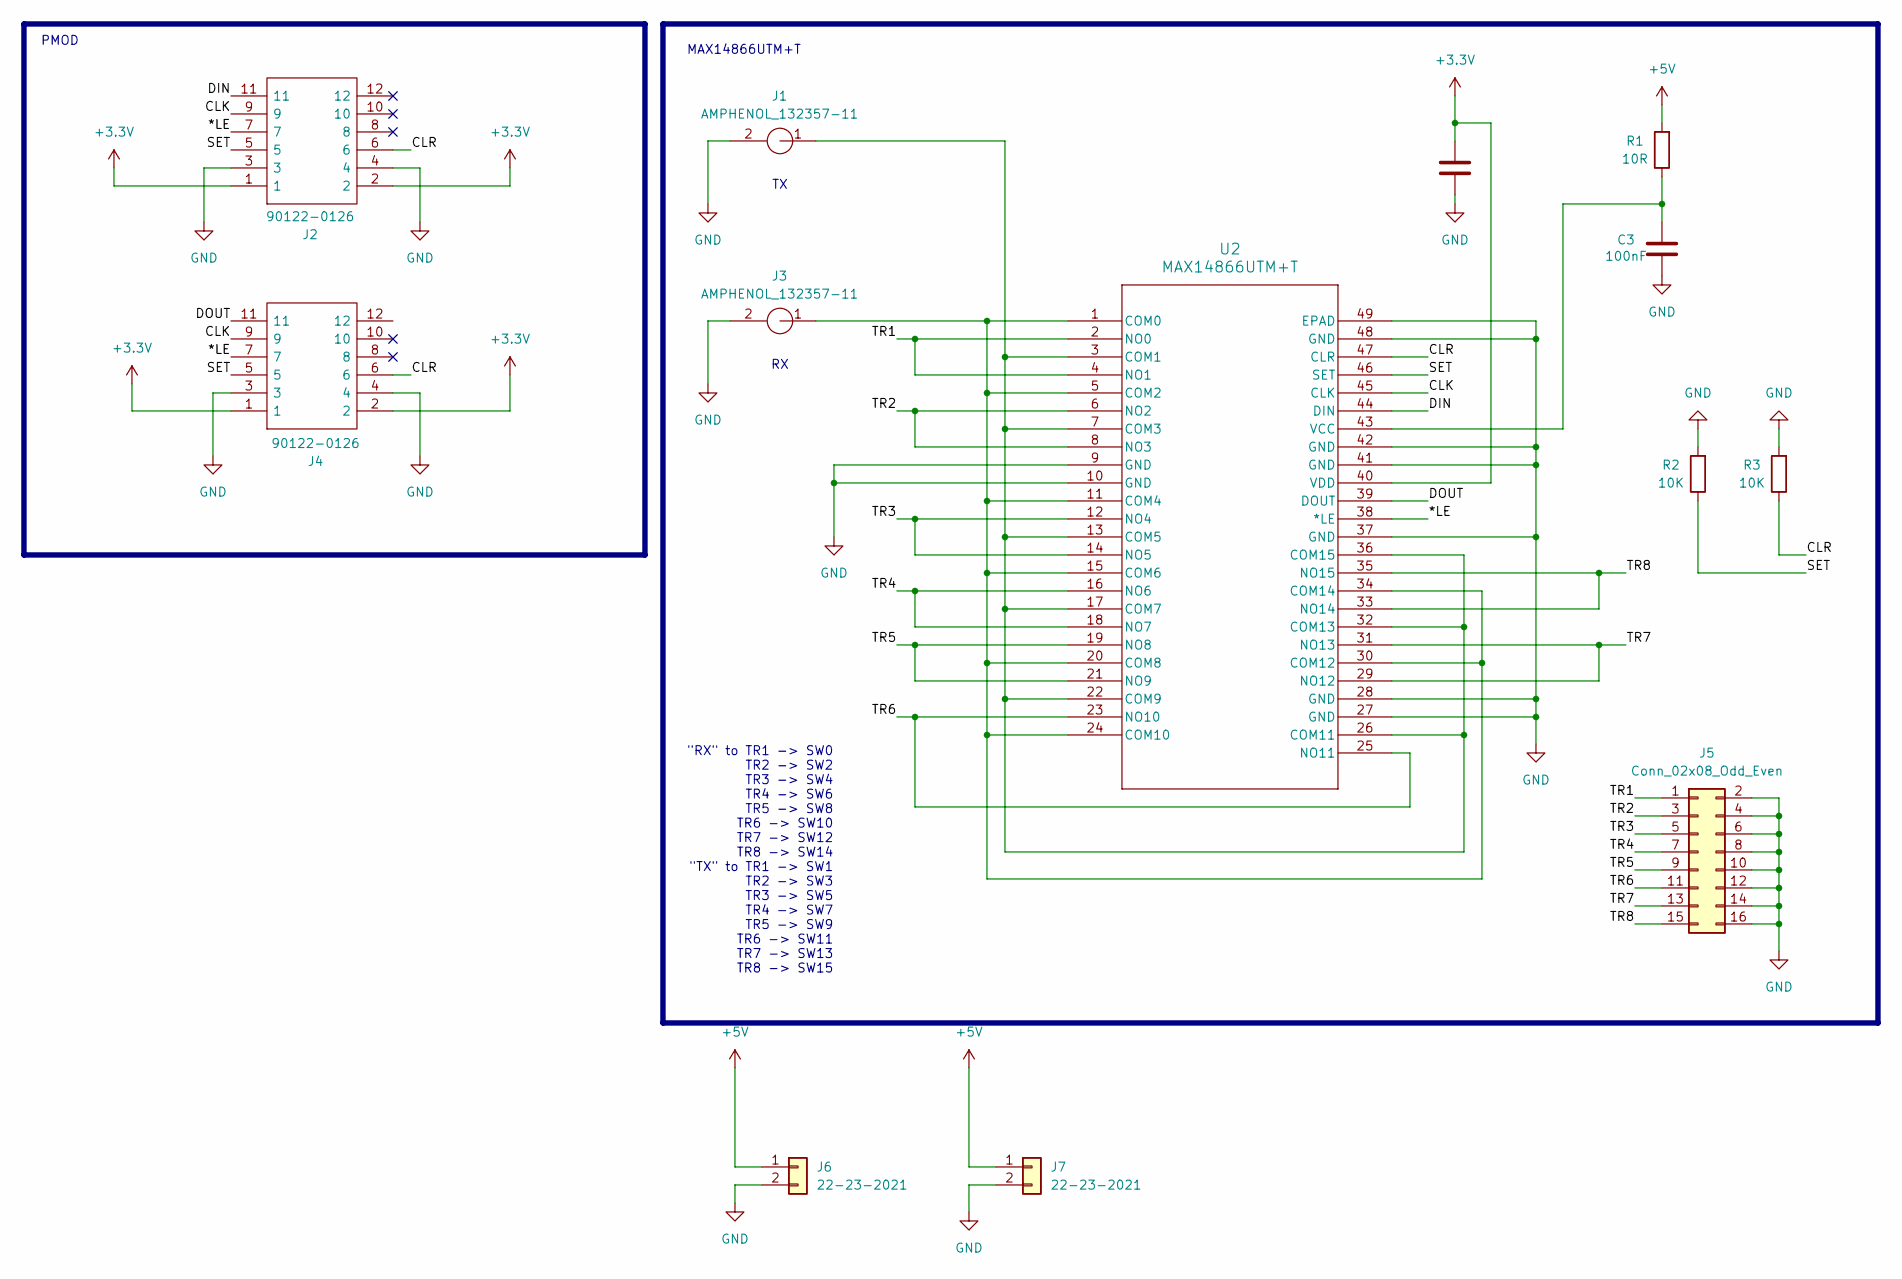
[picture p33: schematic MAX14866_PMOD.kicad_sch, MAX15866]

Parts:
C2: 1uF; C_1206_3216Metric
C3: 100nF; C_1206_3216Metric
J1, J3: AMPHENOL_132357-11; AMPHENOL_132357-11-MOD; Mouser Part Number 530-142-0701-801
J2: 90122-0126; PinHeader_2x06_P2.54mm_Horizontal; Mouser Part Number 710-613012243121
J4: 90122-0126; PinSocket_2x06_P2.54mm_Horizontal; Mouser Part Number 710-613012243121
J5: Conn_02x08_Odd_Even; PinHeader_2x08_P2.54mm_Vertical
J6: 22-23-2021; PinSocket_2x01_P2.54mm_Horizontal; MPN 22-23-2021
J7: 22-23-2021; PinHeader_2x01_P2.54mm_Horizontal; MPN 22-23-2021
R1: 10R; R_1206_3216Metric
R2, R3: 10K; R_1206_3216Metric
U2: MAX14866UTM+T; 21-0144H_T4877-6_MXM

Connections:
+3.3V: C2.2, J2.1, J2.2, J4.1, J4.2, U2.40 (VDD)
+5V: J6.1, J7.1, R1.2
/*LE: J2.7, J4.7, U2.38 (*LE)
/CLK: J2.9, J4.9, U2.45 (CLK)
/CLR: J2.6, J4.6, R3.1, U2.47 (CLR)
/DIN: J2.11, U2.44 (DIN)
/DOUT: J4.11, U2.39 (DOUT)
/SET: J2.5, J4.5, R2.1, U2.46 (SET)
/TR1: J5.1, U2.2 (NO0), U2.4 (NO1)
/TR2: J5.3, U2.6 (NO2), U2.8 (NO3)
/TR3: J5.5, U2.12 (NO4), U2.14 (NO5)
/TR4: J5.7, U2.16 (NO6), U2.18 (NO7)
/TR5: J5.9, U2.19 (NO8), U2.21 (NO9)
/TR6: J5.11, U2.23 (NO10), U2.25 (NO11)
/TR7: J5.13, U2.29 (NO12), U2.31 (NO13)
/TR8: J5.15, U2.33 (NO14), U2.35 (NO15)
GND: C2.1, C3.1, J1.2, J2.3, J2.4, J3.2, J4.3, J4.4, J5.2, J5.4, J5.6, J5.8, J5.10, J5.12, J5.14, J5.16, J6.2, J7.2, R2.2, R3.2, U2.9 (GND), U2.10 (GND), U2.27 (GND), U2.28 (GND), U2.37 (GND), U2.41 (GND), U2.42 (GND), U2.48 (GND), U2.49 (EPAD)
unnamed: J3.1, U2.1 (COM0), U2.5 (COM2), U2.11 (COM4), U2.15 (COM6), U2.20 (COM8), U2.24 (COM10), U2.30 (COM12), U2.34 (COM14)
unnamed: J1.1, U2.3 (COM1), U2.7 (COM3), U2.13 (COM5), U2.17 (COM7), U2.22 (COM9), U2.26 (COM11), U2.32 (COM13), U2.36 (COM15)
unnamed: C3.2, R1.1, U2.43 (VCC)

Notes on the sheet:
PMOD
MAX14866UTM+T
"RX" to TR1 -> SW0 TR2 -> SW2 TR3 -> SW4 TR4 -> SW6 TR5 -> SW8 TR6 -> SW10 TR7 -> SW12 TR8 -> SW14 "TX" to TR1 -> SW1 TR2 -> SW3 TR3 -> SW5 TR4 -> SW7 TR5 -> SW9 TR6 -> SW11 TR7 -> SW13 TR8 -> SW15

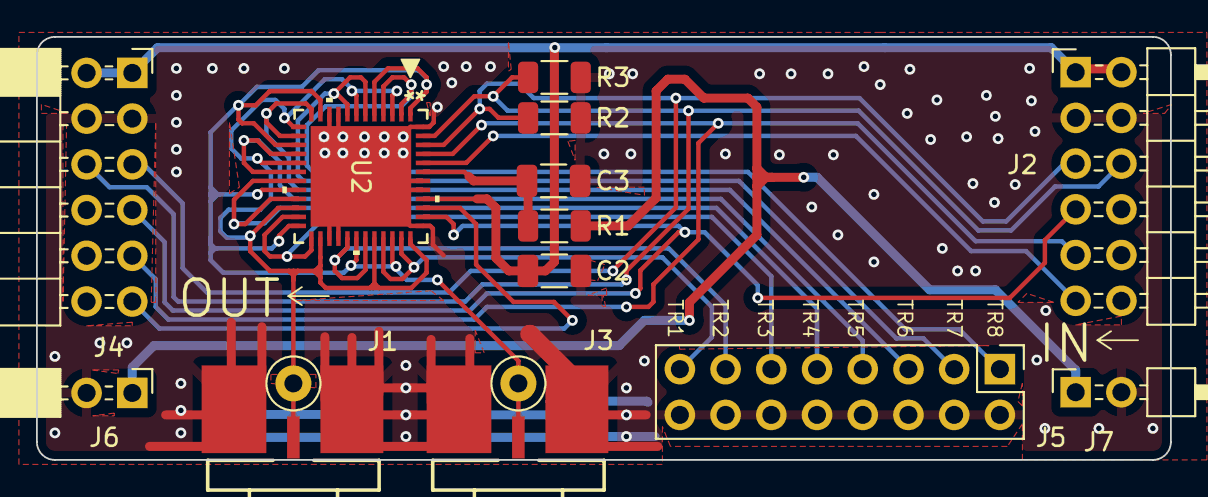
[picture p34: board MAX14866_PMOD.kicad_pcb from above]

Board: 2 copper layers, 63.0 x 23.5 mm, 13 parts (0 on the bottom side), 20 nets.

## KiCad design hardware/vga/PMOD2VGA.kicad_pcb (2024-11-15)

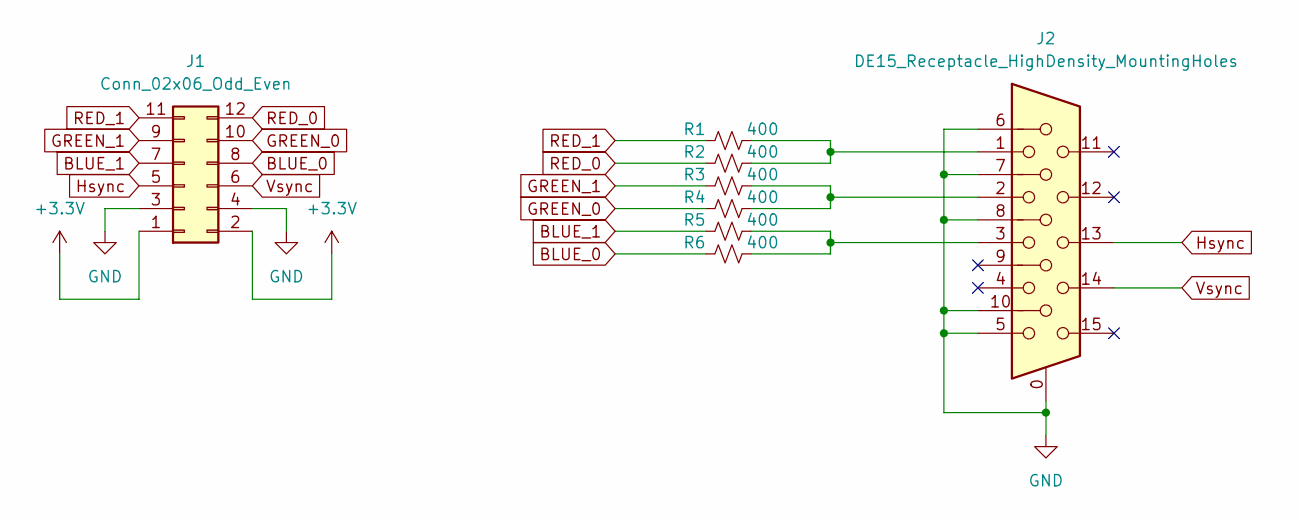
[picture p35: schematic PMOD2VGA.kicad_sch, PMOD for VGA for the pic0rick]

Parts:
J1: Conn_02x06_Odd_Even; PinHeader_2x06_P2.54mm_Horizontal
J2: DE15_Receptacle_HighDensity_MountingHoles; DSUB-15-HD_Female_Horizontal_P2.29x1.98mm_EdgePinOffset3.03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
R1, R2, R3, R4, R5, R6: 400; R_1206_3216Metric

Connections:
+3.3V: J1.1, J1.2
BLUE_0: J1.8, R6.1
BLUE_1: J1.7, R5.1
GND: J1.3, J1.4, J2.0, J2.5, J2.6, J2.7, J2.8, J2.10
GREEN_0: J1.10, R4.1
GREEN_1: J1.9, R3.1
Hsync: J1.5, J2.13
unnamed: J2.1, R1.2, R2.2
unnamed: J2.2, R3.2, R4.2
unnamed: J2.3, R5.2, R6.2
RED_0: J1.12, R2.1
RED_1: J1.11, R1.1
Vsync: J1.6, J2.14

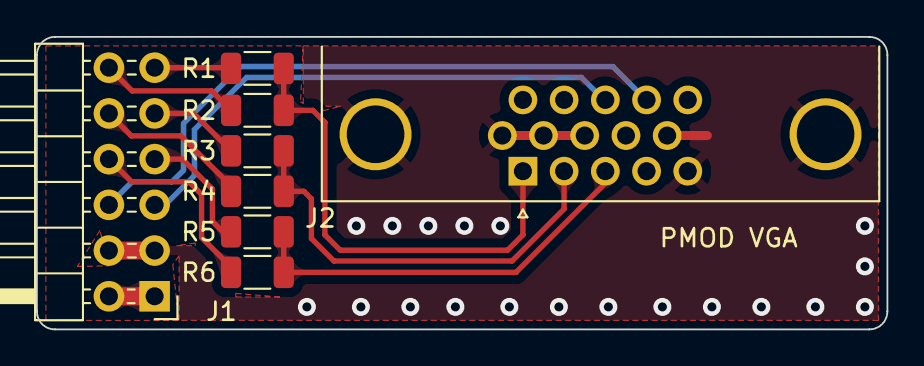
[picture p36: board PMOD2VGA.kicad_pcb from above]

Board: 2 copper layers, 47.2 x 16.2 mm, 8 parts (0 on the bottom side), 13 nets.

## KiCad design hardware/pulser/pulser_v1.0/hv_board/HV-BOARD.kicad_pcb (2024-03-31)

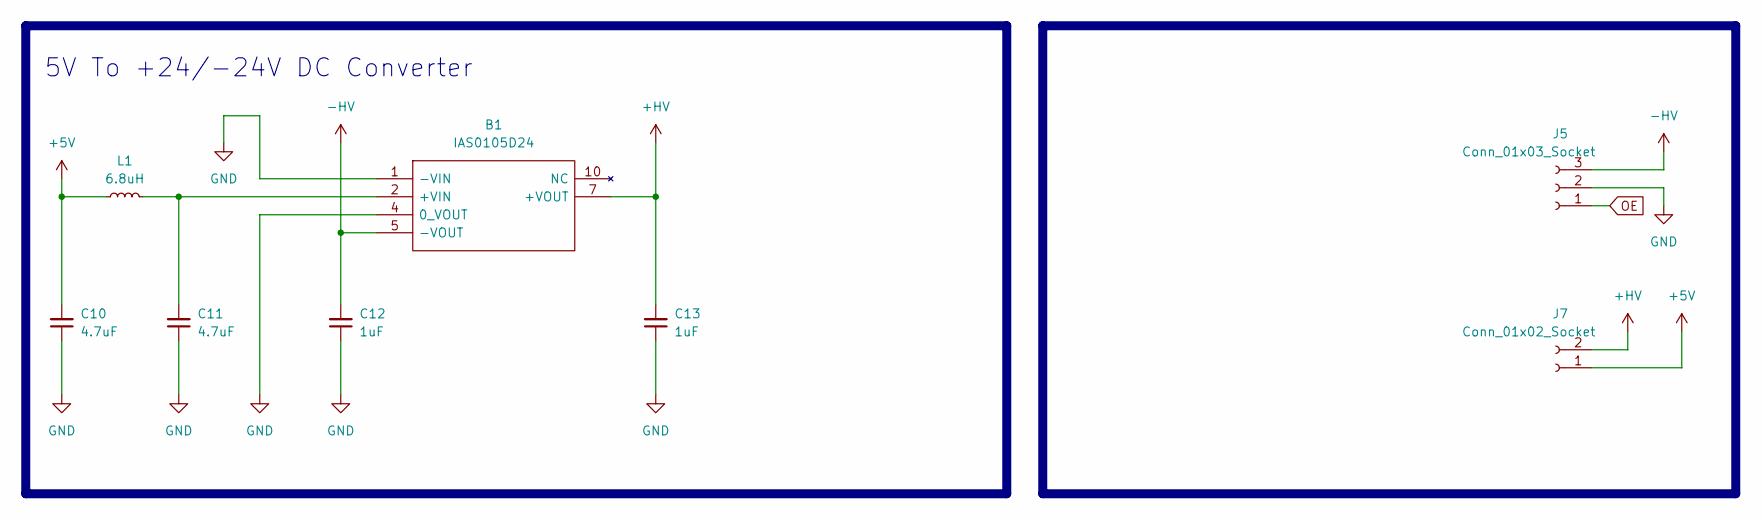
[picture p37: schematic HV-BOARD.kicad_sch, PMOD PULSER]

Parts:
B1: IAS0105D24; Mouser Part Number 209-IAS0105D09
C10, C11: 4.7uF; C_1206_3216Metric
C12, C13: 1uF; C_1206_3216Metric
J5: Conn_01x03_Socket; PinSocket_1x03_P2.54mm_Vertical
J7: Conn_01x02_Socket; PinSocket_1x02_P2.54mm_Vertical
L1: 6.8uH; L_1206_3216Metric; MPN ILSB1206ER6R8K

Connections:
+5V: C10.2, J7.1, L1.1
+HV: B1.7 (+VOUT), C13.2, J7.2
-HV: B1.5 (-VOUT), C12.2, J5.3
GND: B1.1 (-VIN), B1.4 (0_VOUT), C10.1, C11.1, C12.1, C13.1, J5.2
unnamed: B1.2 (+VIN), C11.2, L1.2
OE: J5.1

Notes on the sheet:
5V To +24/-24V DC Converter

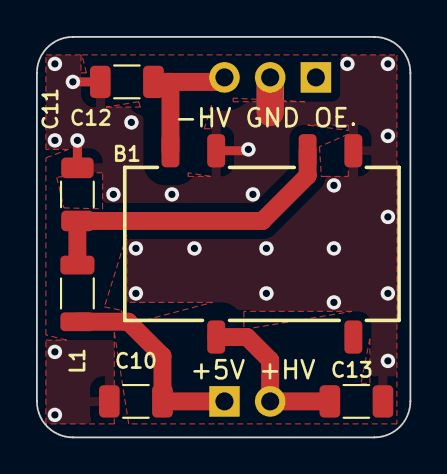
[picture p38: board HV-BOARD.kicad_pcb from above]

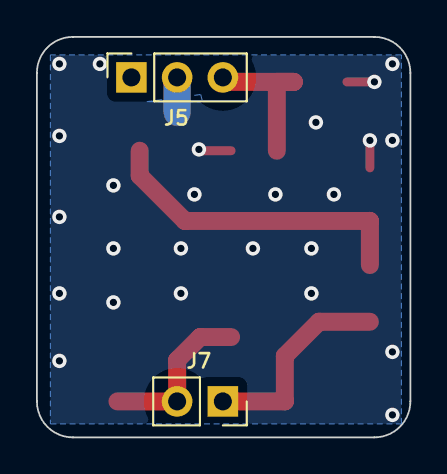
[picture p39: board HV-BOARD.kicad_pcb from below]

Board: 2 copper layers, 20.7 x 22.2 mm, 8 parts (2 on the bottom side), 5 nets.

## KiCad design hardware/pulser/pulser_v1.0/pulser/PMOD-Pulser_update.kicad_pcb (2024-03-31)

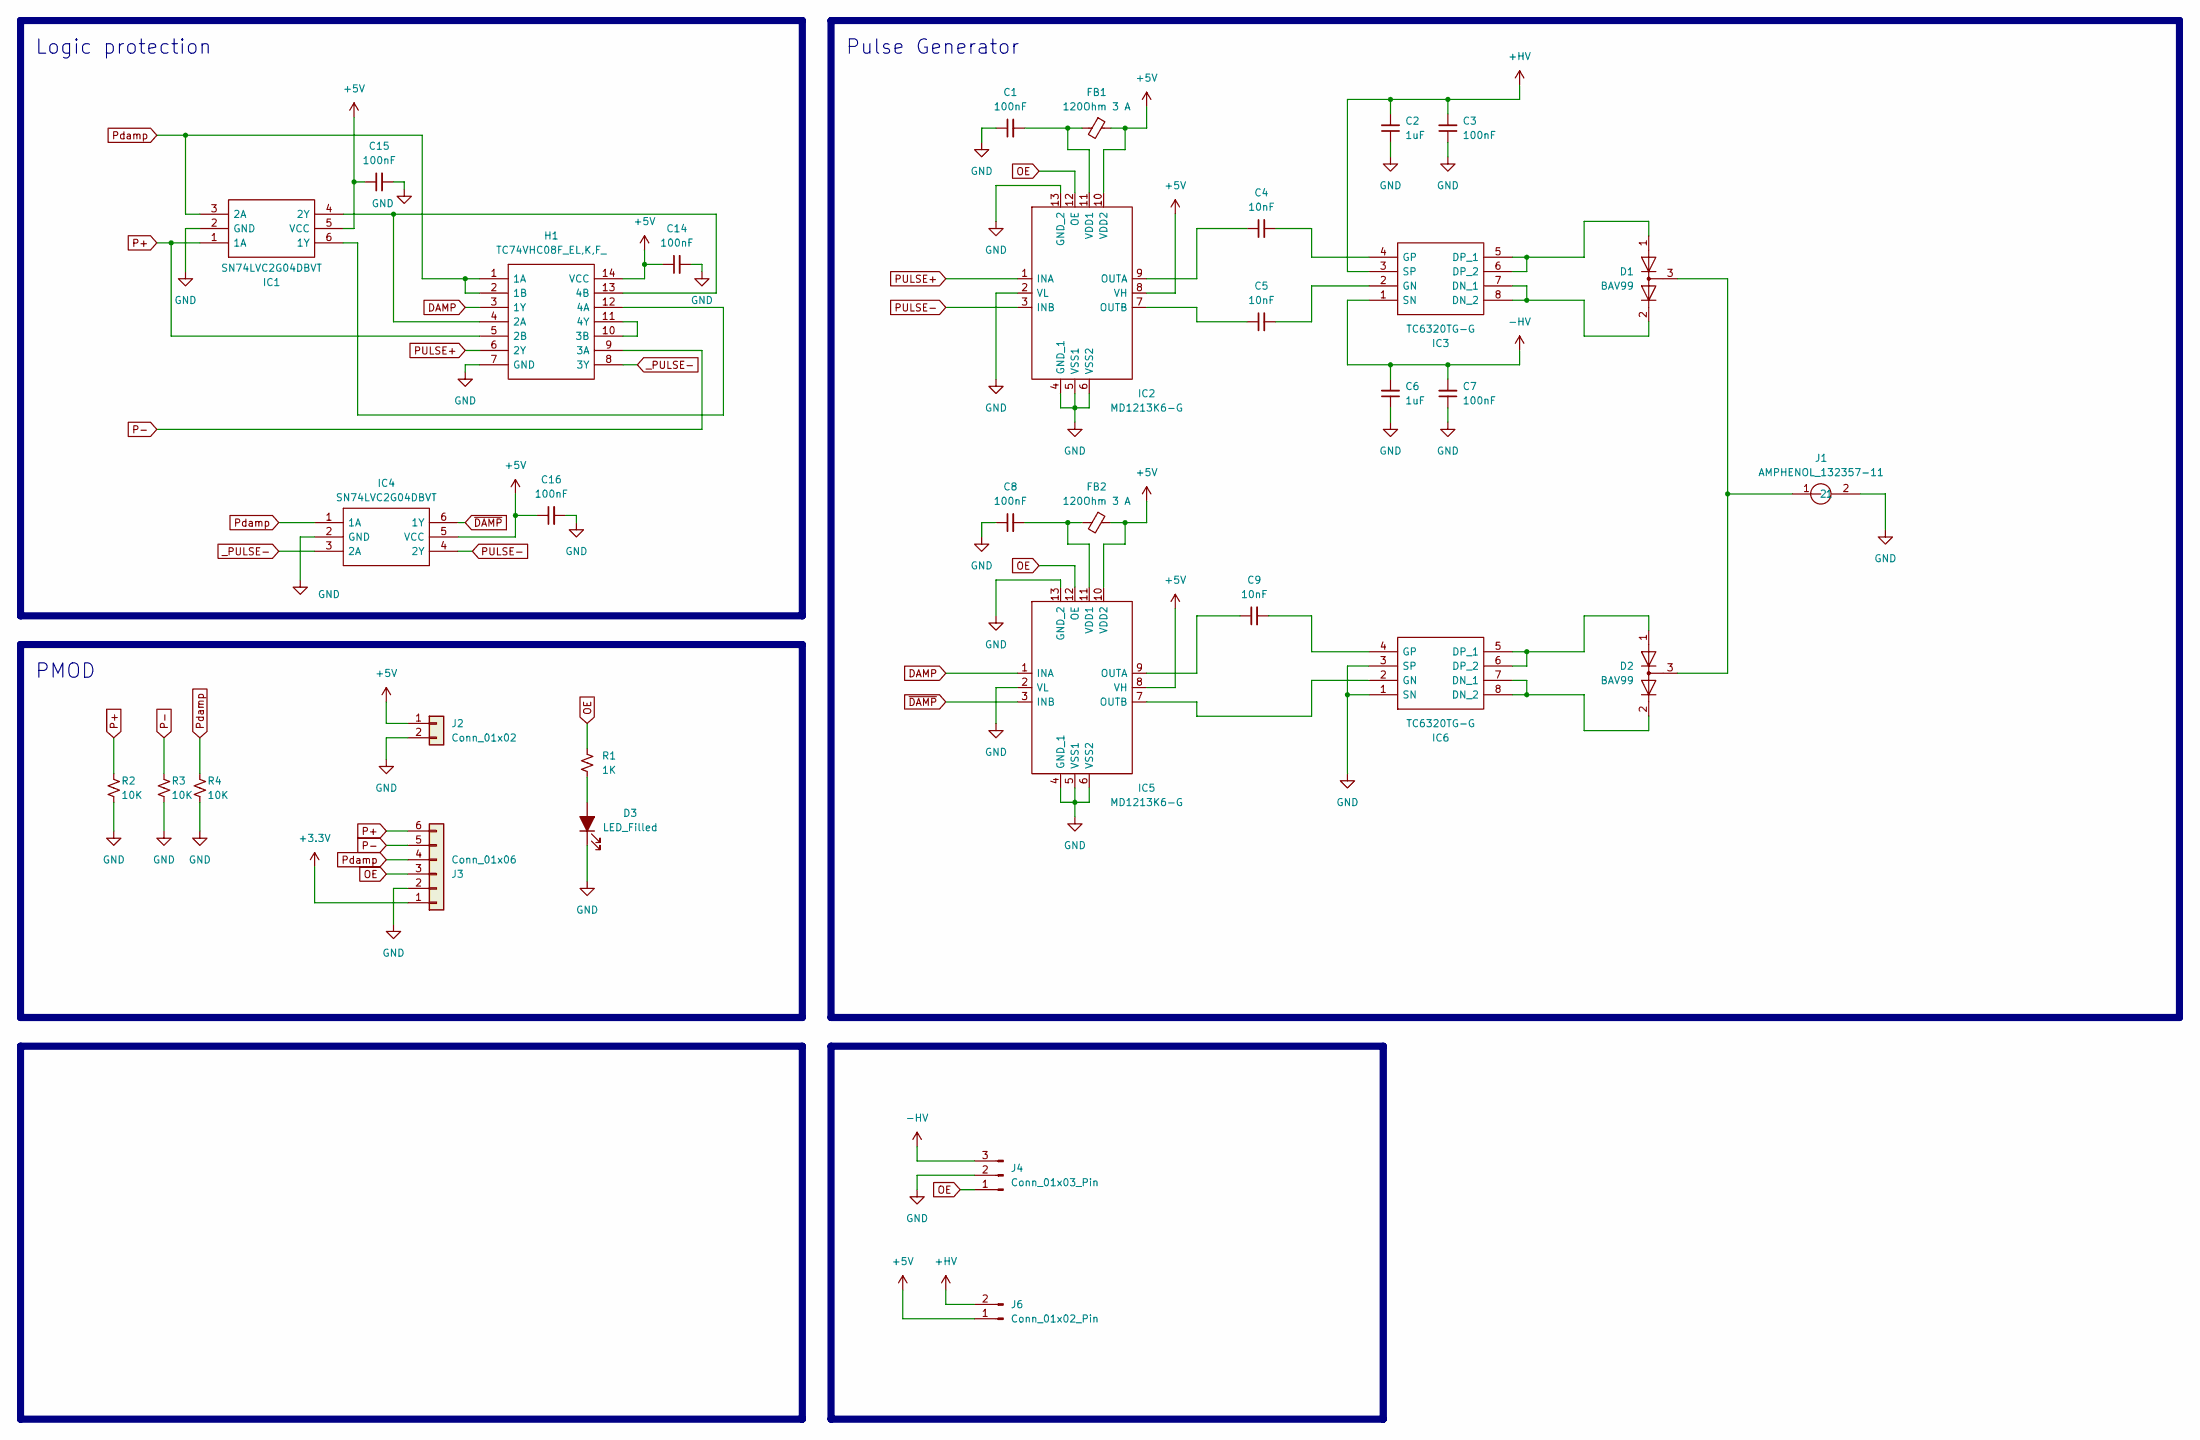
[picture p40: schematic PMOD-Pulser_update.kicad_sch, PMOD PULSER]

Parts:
C1, C3, C7, C8, C14, C15, C16: 100nF; C_1206_3216Metric
C2, C6: 1uF; C_1206_3216Metric
C4, C5, C9: 10nF; C_1206_3216Metric
D1, D2: BAV99; SOT-23; MPN BAV99
D3: LED_Filled; D_0805_2012Metric
FB1, FB2: 120Ohm 3 A; L_1206_3216Metric; MPN 742792113
H1: TC74VHC08F_EL,K,F_; SOIC127P780X190-14N; Mouser Part Number 757-TC74VHC08FELKF
IC1, IC4: SN74LVC2G04DBVT; SN74LVC2G04DBV; Mouser Part Number 595-SN74LVC2G04DBVT
IC2, IC5: MD1213K6-G; MD1213; Mouser Part Number 689-MD1213K6-G
IC3, IC6: TC6320TG-G; SOIC127P600X175-8N; Mouser Part Number 689-TC6320TG-G
J1: AMPHENOL_132357-11; Mouser Part Number 530-142-0701-801
J2: Conn_01x02; PinHeader_2x01_P2.54mm_Horizontal
J3: Conn_01x06; PinHeader_1x06_P2.54mm_Horizontal
J4: Conn_01x03_Pin; PinHeader_1x03_P2.54mm_Vertical
J6: Conn_01x02_Pin; PinHeader_1x02_P2.54mm_Vertical
R1: 1K; R_1206_3216Metric
R2, R3, R4: 10K; R_1206_3216Metric

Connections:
+3.3V: J3.1
+5V: C14.1, C15.1, C16.1, FB1.1, FB2.1, H1.14 (VCC), IC1.5 (VCC), IC2.8 (VH), IC2.10 (VDD2), IC4.5 (VCC), IC5.8 (VH), IC5.10 (VDD2), J2.1, J6.1
+HV: C2.2, C3.2, IC3.3 (SP), J6.2
-HV: C6.2, C7.2, IC3.1 (SN), J4.3
DAMP: H1.3 (1Y), IC5.1 (INA)
GND: C1.1, C2.1, C3.1, C6.1, C7.1, C8.1, C14.2, C15.2, C16.2, D3.1 (K), H1.7 (GND), IC1.2 (GND), IC2.2 (VL), IC2.4 (GND_1), IC2.5 (VSS1), IC2.6 (VSS2), IC2.13 (GND_2), IC4.2 (GND), IC5.2 (VL), IC5.4 (GND_1), IC5.5 (VSS1), IC5.6 (VSS2), IC5.13 (GND_2), IC6.1 (SN), IC6.3 (SP), J1.2, J2.2, J3.2, J4.2, R2.2, R3.2, R4.2
unnamed: D1.2 (A), IC3.7 (DN_1), IC3.8 (DN_2)
unnamed: D1.3 (K), D2.3 (K), J1.1
unnamed: D2.2 (A), IC6.7 (DN_1), IC6.8 (DN_2)
unnamed: D3.2 (A), R1.2
unnamed: H1.4 (2A), H1.13 (4B), IC1.4 (2Y)
unnamed: H1.10 (3B), H1.11 (4Y)
unnamed: H1.12 (4A), IC1.6 (1Y)
unnamed: C4.1, IC2.9 (OUTA)
unnamed: C5.1, IC2.7 (OUTB)
unnamed: C1.2, FB1.2, IC2.11 (VDD1)
unnamed: D1.1 (K), IC3.5 (DP_1), IC3.6 (DP_2)
unnamed: C5.2, IC3.2 (GN)
unnamed: C4.2, IC3.4 (GP)
unnamed: C9.1, IC5.9 (OUTA)
unnamed: IC5.7 (OUTB), IC6.2 (GN)
unnamed: C8.2, FB2.2, IC5.11 (VDD1)
unnamed: D2.1 (K), IC6.5 (DP_1), IC6.6 (DP_2)
unnamed: C9.2, IC6.4 (GP)
OE: IC2.12 (OE), IC5.12 (OE), J3.3, J4.1, R1.1
P+: H1.5 (2B), IC1.1 (1A), J3.6, R2.1
P-: H1.9 (3A), J3.5, R3.1
PULSE+: H1.6 (2Y), IC2.1 (INA)
PULSE-: IC2.3 (INB), IC4.4 (2Y)
Pdamp: H1.1 (1A), H1.2 (1B), IC1.3 (2A), IC4.1 (1A), J3.4, R4.1
_PULSE-: H1.8 (3Y), IC4.3 (2A)
~DAMP: IC4.6 (1Y), IC5.3 (INB)

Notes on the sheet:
PMOD
Logic protection
Pulse Generator

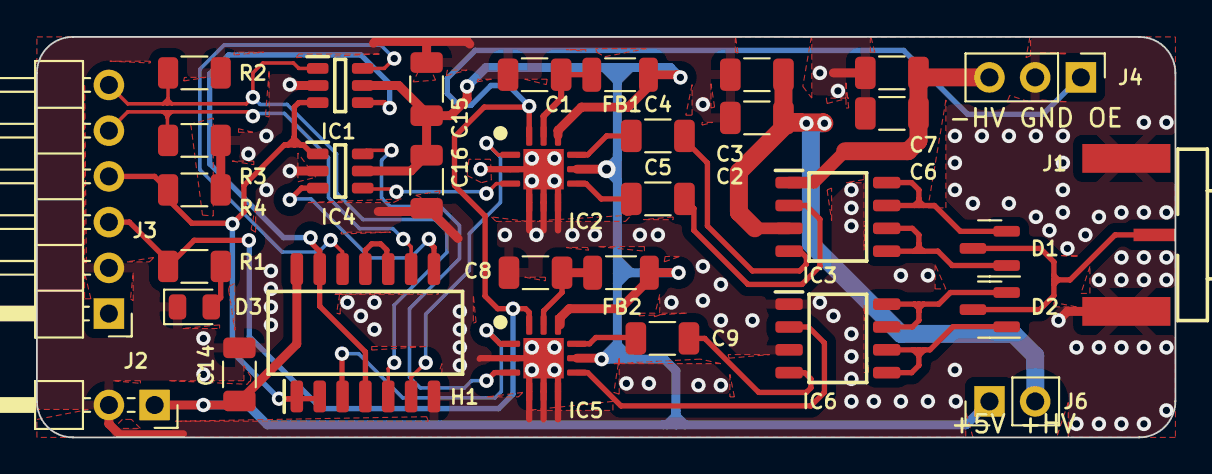
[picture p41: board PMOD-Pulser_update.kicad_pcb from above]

Board: 2 copper layers, 63.2 x 22.2 mm, 33 parts (0 on the bottom side), 31 nets.

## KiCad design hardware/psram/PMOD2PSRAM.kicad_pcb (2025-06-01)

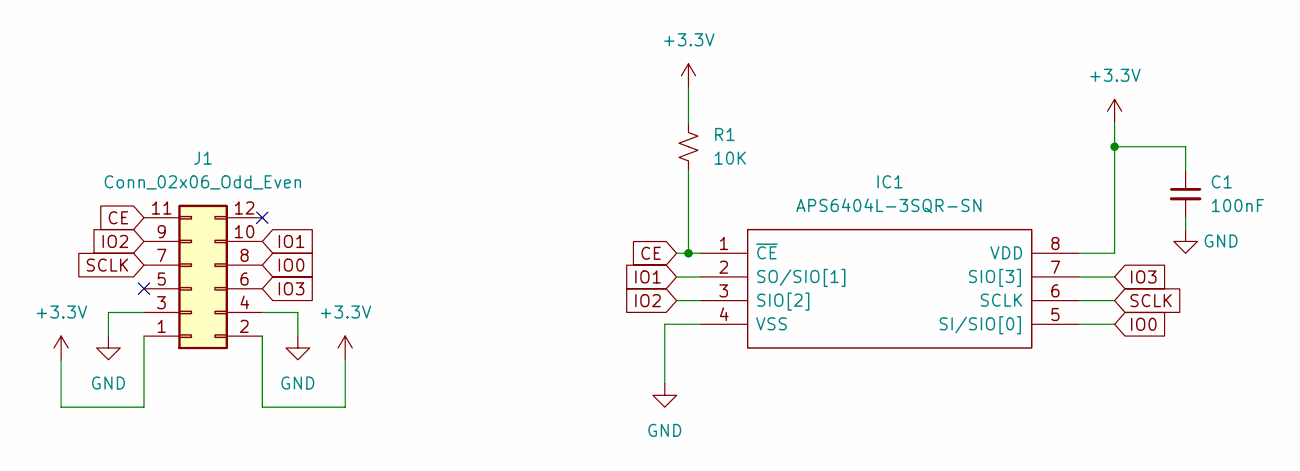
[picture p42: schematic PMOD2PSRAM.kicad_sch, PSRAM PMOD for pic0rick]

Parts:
C1: 100nF; C_1206_3216Metric
IC1: APS6404L-3SQR-SN; SOIC127P600X175-8N; Mouser Part Number 878-APS6404L-3SQR-SN
J1: Conn_02x06_Odd_Even; PinHeader_2x06_P2.54mm_Horizontal
R1: 10K; R_1206_3216Metric

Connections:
+3.3V: C1.1, IC1.8 (VDD), J1.1, J1.2, R1.1
CE: IC1.1 (~CE), J1.11, R1.2
GND: C1.2, IC1.4 (VSS), J1.3, J1.4
IO0: IC1.5 (SI/SIO[0]), J1.8
IO1: IC1.2 (SO/SIO[1]), J1.10
IO2: IC1.3 (SIO[2]), J1.9
IO3: IC1.7 (SIO[3]), J1.6
SCLK: IC1.6 (SCLK), J1.7

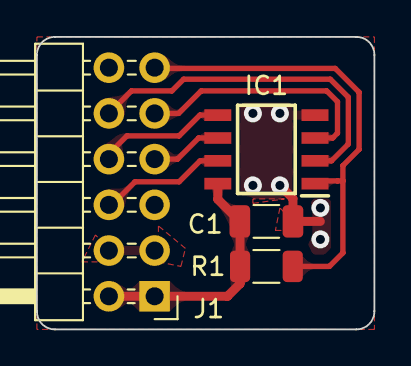
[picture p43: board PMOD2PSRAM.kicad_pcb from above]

Board: 2 copper layers, 18.8 x 16.2 mm, 4 parts (0 on the bottom side), 8 nets.

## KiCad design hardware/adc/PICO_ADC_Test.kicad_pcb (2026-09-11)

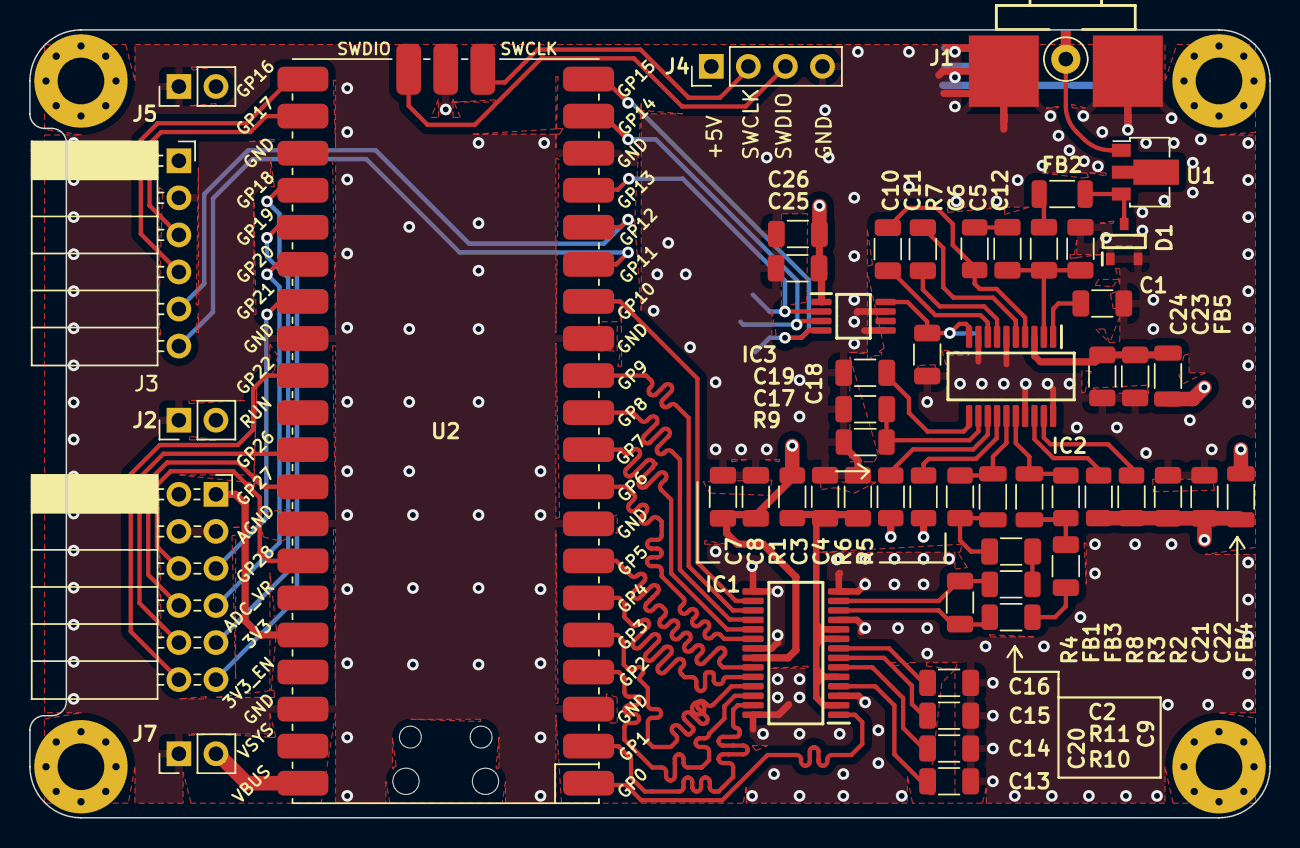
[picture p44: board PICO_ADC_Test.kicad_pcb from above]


Board: 4 copper layers, 85.0 x 54.0 mm, 59 parts (4 on the bottom side), 63 nets.

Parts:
C1, C2, C4, C5, C8, C9, C10, C11, C13, C14, C15, C16, C17, C19, C22, C24, C26: 100nF; C_1206_3216Metric
C3, C7: 4.7uF; C_1206_3216Metric
C6: 18nF; C_1206_3216Metric
C12: 22pF; C_1206_3216Metric
C18, C21, C23: 1nF; C_1206_3216Metric
C20: 50pF; C_1206_3216Metric
C25: 10uF; C_1206_3216Metric
D1: BAV99-7-F; SOT95P240X120-3N
FB1, FB2, FB3, FB4, FB5: ILHB1206ER750V; L_1206_3216Metric
IC1: ADC10065CIMT_NOPB; SOP65P640X120-28N
IC2: AD8331ARQZ; SOP64P600X175-20N
IC3: MCP4812-E_MS; MCP4812-EMS
J1: AMPHENOL_132357-11
J2, J5, J7: SSQ-101-02-L-Q-RA; PinHeader_1x02_P2.54mm_Vertical
J3: 61300611121; PinSocket_1x06_P2.54mm_Horizontal
J4: 61300411121; PinHeader_1x04_P2.54mm_Vertical
J6: 90122-0126; PinSocket_2x06_P2.54mm_Horizontal
R1, R10, R11: 18R; R_1206_3216Metric
R2, R3, R5, R6: 10K; R_1206_3216Metric
R4, R8: 100R; R_1206_3216Metric
R7: 280R; R_1206_3216Metric
R9: 12K; R_1206_3216Metric
TP1, TP2, TP3, TP4: TestPoint; TestPoint_Pad_D1.0mm
U1: MD0100N8-G; SOT-89-3
U2: Pico; RPi_Pico_SMD

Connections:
5VLNA: C23.1, C24.1, FB5.2, IC2.3 (VPSL)
5VVGA: C21.1, C22.1, FB4.1, R2.1, R3.1, R5.1, R6.1
+3.3V: C7.1, C8.1, C25.1, C26.1, IC1.22 (VDDIO), IC3.1 (VDD), J3.1, J6.1, J6.2, R1.1, U2.36 (3V3)
+5V: FB4.2, FB5.1, J2.2, J4.1, J5.2, J7.2, U2.40 (VBUS)
ADC_CLK: IC1.1 (CLK), U2.1 (GPIO0)
CS: IC3.2 (~CS), TP1.1, U2.17 (GPIO13)
D0: IC1.27 (D0), U2.2 (GPIO1)
D1: IC1.26 (D1), U2.4 (GPIO2)
D2: IC1.25 (D2), U2.5 (GPIO3)
D3: IC1.24 (D3), U2.6 (GPIO4)
D4: IC1.23 (D4), U2.7 (GPIO5)
D5: IC1.20 (D5), U2.9 (GPIO6)
D6: IC1.19 (D6), U2.10 (GPIO7)
D7: IC1.18 (D7), U2.11 (GPIO8)
D8: IC1.17 (D8), U2.12 (GPIO9)
D9: IC1.16 (D9), U2.14 (GPIO10)
DAC_G: C18.1, IC2.10 (GAIN), IC3.8 (VOUTA), TP4.1
GND: C1.1, C3.2, C4.2, C7.2, C8.2, C12.2, C13.2, C14.2, C15.2, C16.2, C17.2, C18.2, C19.2, C21.2, C22.2, C23.2, C24.2, C25.2, C26.2, D1.1, D1.2, IC1.3 (VSSA_1), IC1.11 (VSSA_2), IC1.14 (VSSA_3), IC1.15 (DF), IC1.21 (VSSIO), IC1.28 (STBY), IC2.6 (COML), IC2.9 (MODE), IC2.17 (COMM_1), IC2.20 (COMM_2), IC3.5 (~LDAC), IC3.7 (VSS), J1.2, J2.1, J3.2, J4.4, J5.1, J6.3, J6.4, J7.1, R9.2, U2.3 (GND), U2.8 (GND), U2.13 (GND), U2.18 (GND), U2.23 (GND), U2.28 (GND), U2.33 (AGND), U2.38 (GND), U2.42 (GND)
GPIO11: J3.6, U2.15 (GPIO11)
GPIO12: J3.5, U2.16 (GPIO12)
GPIO16: J3.4, U2.21 (GPIO16)
GPIO17: J3.3, U2.22 (GPIO17)
GPIO18: J6.11, U2.24 (GPIO18)
GPIO19: J6.9, U2.25 (GPIO19)
GPIO20: J6.7, U2.26 (GPIO20)
GPIO21: J6.5, U2.27 (GPIO21)
GPIO22: J6.12, U2.29 (GPIO22)
GPIO26: J6.10, U2.31 (GPIO26_ADC0)
GPIO27: J6.8, U2.32 (GPIO27_ADC1)
GPIO28: J6.6, U2.34 (GPIO28_ADC2)
MOSI: IC3.4 (SDI), TP3.1, U2.20 (GPIO15)
unnamed: C2.1, FB1.2, R4.2
unnamed: C5.1, FB2.2
unnamed: C6.2, R7.1
unnamed: C9.1, FB3.2, R8.2
unnamed: C3.1, C4.1, IC1.2 (VDDA_1), IC1.5 (IRS), IC1.9 (VDDA_2), IC1.10 (VDDA_3), R1.2
unnamed: C13.1, IC1.4 (VCOM)
unnamed: C20.2, IC1.13 (VIN+), R11.1
unnamed: C20.1, IC1.12 (VIN-), R10.1
unnamed: C14.1, IC1.6 (VREF)
unnamed: C16.1, IC1.8 (VREFB)
unnamed: C15.1, IC1.7 (VREFT)
unnamed: IC2.19 (ENBL), R2.2
unnamed: IC2.18 (ENBV), R3.2
unnamed: IC2.13 (HILO), R6.2
unnamed: C5.2, C6.1, C12.1, IC2.2 (INH)
unnamed: C1.2, IC2.1 (LMD)
unnamed: C10.1, IC2.4 (LON), R7.2
unnamed: C11.1, IC2.5 (LOP)
unnamed: C17.1, IC2.12 (RCLMP), R9.1
unnamed: C19.1, IC2.11 (VCM)
unnamed: C10.2, IC2.8 (VIN)
unnamed: C11.2, IC2.7 (VIP)
unnamed: IC2.14 (VPOS), R5.2
unnamed: J1.1, U1.1 (A)
unnamed: D1.3, FB2.1, U1.3 (B)
SCLK: IC3.3 (SCK), TP2.1, U2.19 (GPIO14)
SWCLK: J4.2, U2.41 (SWCLK)
SWDIO: J4.3, U2.43 (SWDIO)
TO_ADC_H: C2.2, R11.2
TO_ADC_L: C9.2, R10.2
VOH: FB1.1, IC2.15 (VOH), R4.1
VOL: FB3.1, IC2.16 (VOL), R8.1

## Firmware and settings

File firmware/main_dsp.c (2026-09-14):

#include <math.h>
#include <stdarg.h>
#include <stdio.h>
#include <stdlib.h>
#include <string.h>

#include "pico/multicore.h"
#include "pico/binary_info.h"
#include "pico/bootrom.h"
#include "pico/stdlib.h"

#include "acquisition.h"
#include "dac.h"
#include "dsp.h"
#include "pipeline.h"
#include "u4rk.h"
#include "usb_transport.h"
#include "version.h"
#include "version_git.h"
#ifdef MUX
#include "max/max14866.h"
#endif

#define U4RK_COMMAND_BUFFER_SIZE 160u
#define U4RK_RESPONSE_BUFFER_SIZE 512u
#define U4RK_CONTROL_TIMEOUT_MS 2000u

typedef struct {
    bool active;
    u4rk_payload_type_t type;
    uint32_t rate_hz;
    uint32_t interval_us;
    uint64_t next_capture_us;
} stream_state_t;

static stream_state_t stream;
static bool capture_inflight;
static uint8_t capture_raw_index;
static u4rk_capture_job_t capture_job;
static uint32_t next_sequence;
static float alaw_reference = U4RK_ALAW_DEFAULT_REFERENCE;

static char command_buffer[U4RK_COMMAND_BUFFER_SIZE];
static size_t command_length;
static char response_buffer[U4RK_RESPONSE_BUFFER_SIZE];

static bool output_slot_active;
static uint8_t active_output_slot;
static uint32_t active_output_sequence;
static uint32_t active_output_session;
static bool stop_pending;
static bool dma_fault_pending;
static bool legacy_capture_pending;
static uint32_t legacy_capture_sequence;

static bool selftest_active;
static bool selftest_frame_pending;
static uint32_t selftest_pending_sequence;
static uint8_t selftest_case;
static u4rk_payload_type_t selftest_type;

/* Jobs and output frames are tagged so work from a closed CDC session can
 * never be mistaken for work belonging to the next host connection. */
static uint32_t usb_session_id = 1u;
static bool usb_was_mounted;

static uint16_t legacy_read_buffer[U4RK_MAX_SAMPLE_COUNT];

static bool send_formatted(const char *prefix, const char *format, va_list args) {
    int used = snprintf(response_buffer, sizeof(response_buffer), "%s", prefix);
    if (used < 0 || (size_t)used >= sizeof(response_buffer)) {
        return false;
    }
    int added = vsnprintf(response_buffer + used, sizeof(response_buffer) - used,
                          format, args);
    if (added < 0) {
        return false;
    }
    size_t length = strnlen(response_buffer, sizeof(response_buffer));
    if (length + 2u >= sizeof(response_buffer)) {
        length = sizeof(response_buffer) - 3u;
    }
    response_buffer[length++] = '\r';
    response_buffer[length++] = '\n';
    return u4rk_usb_write_blocking(response_buffer, length,
                                    U4RK_CONTROL_TIMEOUT_MS);
}

static bool send_ok(const char *format, ...) {
    va_list args;
    va_start(args, format);
    bool result = send_formatted("OK ", format, args);
    va_end(args);
    return result;
}

static bool send_error(const char *code, const char *format, ...) {
    int prefix_length =
        snprintf(response_buffer, sizeof(response_buffer), "ERR %s ", code);
    if (prefix_length < 0 ||
        (size_t)prefix_length >= sizeof(response_buffer)) {
        return false;
    }
    va_list args;
    va_start(args, format);
    int added = vsnprintf(response_buffer + prefix_length,
                          sizeof(response_buffer) - (size_t)prefix_length,
                          format, args);
    va_end(args);
    if (added < 0) {
        return false;
    }
    size_t length = strnlen(response_buffer, sizeof(response_buffer));
    if (length + 2u >= sizeof(response_buffer)) {
        length = sizeof(response_buffer) - 3u;
    }
    response_buffer[length++] = '\r';
    response_buffer[length++] = '\n';
    return u4rk_usb_write_blocking(response_buffer, length,
                                    U4RK_CONTROL_TIMEOUT_MS);
}

static bool parse_u32(const char *text, uint32_t *value) {
    if (text == NULL || *text == '\0' || *text == '-') {
        return false;
    }
    char *end;
    unsigned long parsed = strtoul(text, &end, 10);
    if (*end != '\0' || parsed > UINT32_MAX) {
        return false;
    }
    *value = (uint32_t)parsed;
    return true;
}

static bool parse_float(const char *text, float *value) {
    if (text == NULL || *text == '\0') {
        return false;
    }
    char *end;
    float parsed = strtof(text, &end);
    if (*end != '\0' || !isfinite(parsed)) {
        return false;
    }
    *value = parsed;
    return true;
}

static bool parse_payload_type(const char *text,
                               u4rk_payload_type_t *type) {
    if (text == NULL) {
        return false;
    }
    if (strcmp(text, "raw") == 0) {
        *type = U4RK_PAYLOAD_RAW;
    } else if (strcmp(text, "envelope") == 0) {
        *type = U4RK_PAYLOAD_ENVELOPE;
    } else if (strcmp(text, "alaw") == 0) {
        *type = U4RK_PAYLOAD_ALAW;
    } else {
        return false;
    }
    return true;
}

static uint32_t maximum_rate(u4rk_payload_type_t type) {
    switch (type) {
        case U4RK_PAYLOAD_RAW:
            return U4RK_RAW_MAX_RATE_HZ;
        case U4RK_PAYLOAD_ENVELOPE:
            return U4RK_ENVELOPE_MAX_RATE_HZ;
        case U4RK_PAYLOAD_ALAW:
            return U4RK_ALAW_MAX_RATE_HZ;
        default:
            return 0u;
    }
}

static bool operation_busy(void) {
    return capture_inflight || legacy_capture_pending || selftest_active ||
           output_slot_active || u4rk_usb_tx_busy() ||
           u4rk_pipeline_has_pending_output() ||
           !u4rk_pipeline_processing_idle();
}

/* Raw captures the long window; envelope/A-law use the fixed FFT length. */
static uint32_t sample_count_for(u4rk_payload_type_t type) {
    return (type == U4RK_PAYLOAD_ENVELOPE || type == U4RK_PAYLOAD_ALAW)
               ? U4RK_SAMPLE_COUNT
               : U4RK_RAW_SAMPLE_COUNT;
}

static bool begin_capture(u4rk_payload_type_t type, uint16_t extra_flags) {
    uint16_t *raw_buffer;
    uint8_t raw_index;
    if (!u4rk_pipeline_claim_raw(&raw_index, &raw_buffer)) {
        return false;
    }

    uint16_t flags = extra_flags;
    if (u4rk_pulser_is_armed()) {
        flags |= U4RK_FLAG_PULSER_ARMED;
    }
    uint32_t count = sample_count_for(type);
    capture_job = (u4rk_capture_job_t){
        .raw_index = raw_index,
        .payload_type = (uint8_t)type,
        .flags = flags,
        .sequence = next_sequence++,
        .session_id = usb_session_id,
        .sample_count = count,
        .sample_rate_hz = U4RK_SAMPLE_RATE_HZ,
        .capture_timestamp_us = time_us_64(),
        .alaw_reference = alaw_reference,
        .pulse = u4rk_pulser_get_config(),
    };
    if (!u4rk_capture_start(raw_buffer, count)) {
        u4rk_pipeline_release_raw(raw_index);
        return false;
    }
    capture_raw_index = raw_index;
    capture_inflight = true;
    return true;
}

static void poll_capture(void) {
    if (!capture_inflight) {
        return;
    }
    u4rk_capture_state_t state = u4rk_capture_poll();
    if (state == U4RK_CAPTURE_DONE) {
        capture_inflight = false;
        u4rk_pipeline_submit(&capture_job);
    } else if (state == U4RK_CAPTURE_DMA_FAULT) {
        capture_inflight = false;
        u4rk_pipeline_release_raw(capture_raw_index);
        stream.active = false;
        dma_fault_pending = true;
    }
}

static void drain_ready_outputs_as_drops(void) {
    uint8_t slot;
    const uint8_t *data;
    size_t size;
    uint32_t sequence;
    uint32_t session_id;
    while (u4rk_pipeline_take_output(
            &slot, &data, &size, &sequence, &session_id)) {
        (void)data;
        (void)size;
        if (selftest_frame_pending && session_id == usb_session_id &&
            sequence == selftest_pending_sequence) {
            selftest_active = false;
            selftest_frame_pending = false;
        }
        u4rk_pipeline_release_output(slot);
        u4rk_pipeline_note_usb_drop();
    }
}

static void advance_selftest(void) {
    selftest_frame_pending = false;
    if (selftest_type == U4RK_PAYLOAD_ALAW) {
        selftest_type = U4RK_PAYLOAD_RAW;
        ++selftest_case;
        if (selftest_case >= u4rk_dsp_selftest_count()) {
            selftest_active = false;
        }
    } else {
        selftest_type =
            (u4rk_payload_type_t)((uint8_t)selftest_type + 1u);
    }
}

static void poll_output(void) {
    if (output_slot_active && !u4rk_usb_tx_busy()) {
        bool failed = u4rk_usb_tx_take_failed();
        u4rk_pipeline_release_output(active_output_slot);
        output_slot_active = false;
        bool was_pending_selftest = selftest_frame_pending &&
            active_output_session == usb_session_id &&
            active_output_sequence == selftest_pending_sequence;
        if (failed) {
            u4rk_pipeline_note_usb_drop();
            if (was_pending_selftest) {
                selftest_active = false;
                selftest_frame_pending = false;
            }
        } else if (was_pending_selftest) {
            advance_selftest();
        }
    }

    if (!output_slot_active && !u4rk_usb_tx_busy() &&
        !stop_pending && !dma_fault_pending) {
        const uint8_t *data;
        size_t size;
        uint8_t slot;
        uint32_t sequence;
        uint32_t session_id;
        while (u4rk_pipeline_take_output(
                &slot, &data, &size, &sequence, &session_id)) {
            if (session_id != usb_session_id) {
                /* Core 1 may finish an old job after its CDC session closes. */
                u4rk_pipeline_release_output(slot);
                u4rk_pipeline_note_usb_drop();
                continue;
            }
            if (u4rk_usb_tx_start(data, size)) {
                output_slot_active = true;
                active_output_slot = slot;
                active_output_sequence = sequence;
                active_output_session = session_id;
            } else {
                u4rk_pipeline_release_output(slot);
                u4rk_pipeline_note_usb_drop();
                /* Never leave a failed self-test transfer permanently busy. */
                if (selftest_frame_pending &&
                    sequence == selftest_pending_sequence) {
                    selftest_active = false;
                    selftest_frame_pending = false;
                }
            }
            break;
        }
    }
}

static void poll_completions(void) {
    uint32_t sequence;
    while (u4rk_pipeline_take_completion(&sequence)) {
        if (legacy_capture_pending && sequence == legacy_capture_sequence) {
            legacy_capture_pending = false;
        }
    }
}

static void schedule_stream(void) {
    if (!stream.active || capture_inflight) {
        return;
    }
    uint64_t now = time_us_64();
    if (now < stream.next_capture_us) {
        return;
    }
    if (!begin_capture(stream.type, 0)) {
        u4rk_pipeline_note_processing_drop();
    }
    stream.next_capture_us += stream.interval_us;
    if (stream.next_capture_us <= now) {
        stream.next_capture_us = now + stream.interval_us;
    }
}

static void schedule_selftest(void) {
    if (!selftest_active || selftest_frame_pending || capture_inflight ||
        output_slot_active || u4rk_usb_tx_busy() ||
        u4rk_pipeline_has_pending_output()) {
        return;
    }

    uint8_t raw_index;
    uint16_t *raw_buffer;
    if (!u4rk_pipeline_claim_raw(&raw_index, &raw_buffer)) {
        return;
    }
    u4rk_dsp_make_selftest(selftest_case, raw_buffer);
    float reference =
        selftest_case == (u4rk_dsp_selftest_count() - 1u)
            ? 128.0f : alaw_reference;
    u4rk_capture_job_t job = {
        .raw_index = raw_index,
        .payload_type = (uint8_t)selftest_type,
        .flags = (uint16_t)(U4RK_FLAG_SELFTEST |
            ((uint16_t)selftest_case << U4RK_FLAG_SELFTEST_CASE_SHIFT)),
        .sequence = next_sequence++,
        .session_id = usb_session_id,
        .sample_count = U4RK_SAMPLE_COUNT,
        .sample_rate_hz = U4RK_SAMPLE_RATE_HZ,
        .capture_timestamp_us = selftest_case,
        .alaw_reference = reference,
        .pulse = u4rk_pulser_get_config(),
    };
    if (u4rk_pipeline_submit(&job)) {
        selftest_pending_sequence = job.sequence;
        selftest_frame_pending = true;
    }
}

static void stop_stream(void) {
    stream.active = false;
    u4rk_pulser_disarm();
    if (capture_inflight) {
        u4rk_capture_abort();
        capture_inflight = false;
        u4rk_pipeline_release_raw(capture_raw_index);
        u4rk_pipeline_note_processing_drop();
    }
    drain_ready_outputs_as_drops();
    stop_pending = true;
}

static void send_version(void) {
    char buf[512];
    int n = snprintf(buf, sizeof(buf),
        "pic0rick firmware v%s\r\n"
        "changes: %s\r\n"
        "board:   %s (%s)\r\n"
#ifdef MUX
        "mux:     enabled (MAX14866)\r\n"
#else
        "mux:     disabled\r\n"
#endif
        "build:   %s\r\n"
        "release: %s\r\n",
        FW_VERSION, FW_CHANGES, FW_BOARD, FW_CHIP, FW_GIT_HASH, FW_RELEASE_URL);
    if (n > 0) {
        u4rk_usb_write_blocking(buf, (size_t)n, U4RK_CONTROL_TIMEOUT_MS);
    }
}

static void reboot_dfu(void) {
    send_ok("rebooting into USB bootloader (BOOTSEL)");
    sleep_ms(100);          /* let the CDC drain the reply */
    reset_usb_boot(0, 0);   /* does not return */
}

static void send_help(void) {
    send_ok(
        "commands=status|help|version|reboot-dfu|"
        "pulser arm|pulser disarm|"
        "pulse config <negative_ns> <damp_ns> <positive_ns> "
        "<neg-first|pos-first>|dac write <0..1023>|"
        "dsp scale <reference>|dsp selftest|"
        "acq <raw|envelope|alaw>|read_raw|read_fft|"
        "stream start <raw|envelope|alaw> <rate_hz>|stream stop|"
#ifdef MUX
        "write mux <hex>|set mux|clear mux|"
#endif
        "start acq|read");
}

static void send_status(void) {
    u4rk_pulse_config_t pulse = u4rk_pulser_get_config();
    u4rk_dsp_metrics_t metrics;
    u4rk_pipeline_get_metrics(&metrics);
    send_ok(
        "board=pic0rick package=RP2350A firmware=%s "
        "dsp_backend=f32-rfft-hilbert "
        "samples=%u sample_rate=%u "
        "pulser=%s pulse=%u/%u/%u/%s dac=%u scale=%.6g "
        "stream=%s/%u drops=%u stages_us=%u/%u/%u/%u/%u/%u "
        "dsp_us=%u worst_us=%u performance=%s "
        "envelope_max_rate=%u alaw_max_rate=%u cmsis=%s",
        PICO_PROGRAM_VERSION_STRING,
        U4RK_SAMPLE_COUNT, U4RK_SAMPLE_RATE_HZ,
        u4rk_pulser_is_armed() ? "armed" : "disarmed",
        pulse.negative_ns, pulse.damp_ns, pulse.positive_ns,
        pulse.order == U4RK_PULSE_NEGATIVE_FIRST ? "neg-first" : "pos-first",
        u4rk_dac_last_value(), (double)alaw_reference,
        stream.active ? "on" : "off", stream.rate_hz,
        u4rk_pipeline_dropped_frames(),
        metrics.preprocess_us, metrics.forward_fft_us, metrics.mask_us,
        metrics.inverse_fft_us, metrics.magnitude_us, metrics.alaw_us,
        metrics.total_us, metrics.worst_total_us,
        metrics.worst_total_us <= U4RK_DSP_TARGET_US
            ? "ok" : "over-budget",
        U4RK_ENVELOPE_MAX_RATE_HZ, U4RK_ALAW_MAX_RATE_HZ,
        U4RK_CMSIS_DSP_VERSION);
}

static void legacy_read(void) {
    uint32_t sample_count = u4rk_pipeline_copy_latest_raw(legacy_read_buffer);
    if (sample_count == 0u) {
        send_error("NO_DATA", "no completed acquisition");
        return;
    }
    char prefix[32];
    int plen = snprintf(prefix, sizeof(prefix), "OK raw-hex %u\r\n",
                        (unsigned)sample_count);
    if (plen < 0 || !u4rk_usb_write_blocking(prefix, (size_t)plen,
                                             U4RK_CONTROL_TIMEOUT_MS)) {
        return;
    }
    char chunk[192];
    size_t used = 0;
    for (uint32_t i = 0; i < sample_count; ++i) {
        int count = snprintf(chunk + used, sizeof(chunk) - used, "%03X%s",
                             legacy_read_buffer[i],
                             i + 1u == sample_count ? "\r\n" : ",");
        if (count < 0) {
            return;
        }
        used += (size_t)count;
        if (used > sizeof(chunk) - 8u || i + 1u == sample_count) {
            if (!u4rk_usb_write_blocking(chunk, used,
                                         U4RK_CONTROL_TIMEOUT_MS)) {
                return;
            }
            used = 0;
        }
    }
}

static void process_command(char *line) {
    char *save;
    char *first = strtok_r(line, " \t", &save);
    if (first == NULL) {
        return;
    }
    char *second = strtok_r(NULL, " \t", &save);

    if (stream.active) {
        if (strcmp(first, "stream") == 0 && second != NULL &&
            strcmp(second, "stop") == 0) {
            stop_stream();
        }
        /* No unframed text is emitted while a stream is active. */
        return;
    }

    if (strcmp(first, "help") == 0 && second == NULL) {
        send_help();
        return;
    }
    if (strcmp(first, "status") == 0 && second == NULL) {
        send_status();
        return;
    }

    if (strcmp(first, "version") == 0 && second == NULL) {
        send_version();
        return;
    }

    if (strcmp(first, "reboot-dfu") == 0 && second == NULL) {
        if (operation_busy()) {
            send_error("BUSY", "operation in progress");
        } else {
            reboot_dfu();
        }
        return;
    }

#ifdef MUX
    if (strcmp(first, "write") == 0 && second != NULL &&
        strcmp(second, "mux") == 0) {
        char *value_text = strtok_r(NULL, " \t", &save);
        char *extra = strtok_r(NULL, " \t", &save);
        if (operation_busy()) {
            send_error("BUSY", "operation in progress");
        } else if (value_text == NULL || extra != NULL) {
            send_error("ARG", "usage: write mux <hex>");
        } else {
            max14866(value_text);  /* parses the value as hexadecimal */
            send_ok("mux=%s", value_text);
        }
        return;
    }
    if (strcmp(first, "set") == 0 && second != NULL &&
        strcmp(second, "mux") == 0) {
        if (operation_busy()) {
            send_error("BUSY", "operation in progress");
        } else {
            max14866_set(NULL);
            send_ok("mux set");
        }
        return;
    }
    if (strcmp(first, "clear") == 0 && second != NULL &&
        strcmp(second, "mux") == 0) {
        if (operation_busy()) {
            send_error("BUSY", "operation in progress");
        } else {
            max14866_clear(NULL);
            send_ok("mux cleared");
        }
        return;
    }
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
int main(void) {
    bi_decl(bi_program_description(
        "pic0rick RP2350A 4096-sample Hilbert envelope and A-law firmware"));
    bi_decl(bi_pin_mask_with_name(0x7ffu, "ADC clock GPIO0 and data GPIO1..10"));
    bi_decl(bi_3pins_with_names(
        U4RK_DAC_CS_PIN, "MCP4812 CS",
        U4RK_DAC_SCK_PIN, "MCP4812 SCK",
        U4RK_DAC_TX_PIN, "MCP4812 MOSI"));
    bi_decl(bi_2pins_with_names(
        U4RK_PULSER_PP_PIN, "PMOD pulser P+",
        U4RK_PULSER_PN_PIN, "PMOD pulser P-"));
    bi_decl(bi_2pins_with_names(
        U4RK_PULSER_PDAMP_PIN, "PMOD pulser PDAMP",
        U4RK_PULSER_OE_PIN, "PMOD pulser OE"));

    /*
     * Pulser safety comes first: all four control pins are driven low before
     * DSP-table generation, USB enumeration, or any command handling.
     */
    u4rk_acquisition_init();
    u4rk_dac_init();
#ifdef MUX
    max14866_init();
#endif
    if (!u4rk_pipeline_init()) {
        u4rk_pulser_disarm();
        while (true) {
            tight_loop_contents();
        }
    }
    multicore_launch_core1(u4rk_pipeline_core1_entry);
    if (!u4rk_usb_init()) {
        u4rk_pulser_disarm();
        while (true) {
            tight_loop_contents();
        }
    }

    while (true) {
        u4rk_usb_task();
        handle_disconnect();
        poll_capture();
        poll_completions();
        poll_output();
        finish_stop_or_fault();
        poll_command_input();
        schedule_stream();
        schedule_selftest();
        tight_loop_contents();
    }
}

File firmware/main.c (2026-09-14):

//---------------------------------------------------------------------------
// INCLUDES
//--------------------------------------------------------------------------
#include <stdio.h>
#include <stdlib.h>
#include <string.h>

#include "pico/stdlib.h"
#include "pico/bootrom.h"

#include "acquisition.h"   // shared pulser + ADC capture (firmware/hw)
#include "dac.h"           // shared spi1 MCP4812 DAC (firmware/hw)
#include "u4rk.h"
#include "version.h"
#include "version_git.h"
#ifdef MUX
#include "max/max14866.h"
#endif

//---------------------------------------------------------------------------
// GLOBALS
//--------------------------------------------------------------------------

typedef void (*command_func_t)(const char *args);

typedef struct
{
    const char *command_name;
    command_func_t func;
} command_t;

// Single-threaded stdio build: one raw capture buffer (8000 samples).
static uint16_t capture_buf[U4RK_RAW_SAMPLE_COUNT];
static bool capture_valid;

//---------------------------------------------------------------------------
// VERSION COMMAND
//--------------------------------------------------------------------------
void version_cmd(const char *args)
{
    printf("pic0rick firmware v%s\n", FW_VERSION);
    printf("changes: %s\n", FW_CHANGES);
    printf("board:   %s (%s)\n", FW_BOARD, FW_CHIP);
#ifdef MUX
    printf("mux:     enabled (MAX14866)\n");
#else
    printf("mux:     disabled\n");
#endif
    printf("build:   %s\n", FW_GIT_HASH);
    printf("release: %s\n", FW_RELEASE_URL);
}

//---------------------------------------------------------------------------
// REBOOT-DFU COMMAND
//--------------------------------------------------------------------------
// Reboot into the RP2040/RP2350 USB bootloader (BOOTSEL / UF2 mass storage,
// colloquially "DFU") so a new UF2 can be flashed without pressing BOOTSEL.
void reboot_dfu_cmd(const char *args)
{
    printf("Rebooting into USB bootloader (BOOTSEL)...\n");
    fflush(stdout);
    sleep_ms(100);          // give USB CDC time to drain the message
    reset_usb_boot(0, 0);   // does not return
}

//---------------------------------------------------------------------------
// DAC COMMAND (shared spi1 MCP4812)
//--------------------------------------------------------------------------
void write_dac_cmd(const char *args)
{
    int value = atoi(args);
    if (value < 0 || value > 1023) {
        printf("DAC value must be 0..1023\n");
        return;
    }
    u4rk_dac_write((uint16_t)value);
    printf("dac=%d\n", value);
}

//---------------------------------------------------------------------------
// START ACQ COMMAND (shared pulser + ADC capture)
//--------------------------------------------------------------------------
// Usage: start acq [pon_ns] [poff_ns] [damp_ns]  (defaults 200/200/2000)
// Mapped onto the shared pulser: positive_ns=pon, negative_ns=poff,
// damp_ns=damp, positive-first. Captures U4RK_RAW_SAMPLE_COUNT (8000) samples.
void start_acq_cmd(const char *args)
{
    uint32_t pon = 200, poff = 200, damp = 2000;
    if (args != NULL) {
        char copy[64];
        strncpy(copy, args, sizeof(copy) - 1);
        copy[sizeof(copy) - 1] = '\0';
        char *tok = strtok(copy, " ");
        if (tok) { pon = (uint32_t)atoi(tok); tok = strtok(NULL, " "); }
        if (tok) { poff = (uint32_t)atoi(tok); tok = strtok(NULL, " "); }
        if (tok) { damp = (uint32_t)atoi(tok); }
    }

    if (!u4rk_pulser_configure(poff, damp, pon, U4RK_PULSE_POSITIVE_FIRST)) {
        printf("pulse config out of range (min 40 ns each)\n");
        return;
    }
    u4rk_pulser_arm();

    if (!u4rk_capture_start(capture_buf, U4RK_RAW_SAMPLE_COUNT)) {
        u4rk_pulser_disarm();
        printf("acquisition busy\n");
        return;
    }
    printf("Acquisition of %u samples started\n",
           (unsigned)U4RK_RAW_SAMPLE_COUNT);

    u4rk_capture_state_t state;
    do {
        state = u4rk_capture_poll();
    } while (state == U4RK_CAPTURE_ACTIVE);
    u4rk_pulser_disarm();

    if (state == U4RK_CAPTURE_DONE) {
        capture_valid = true;
        printf("Acquisition ended\n");
    } else {
        capture_valid = false;
        printf("ADC timeout occured\n");
    }
}

//---------------------------------------------------------------------------
// READ COMMAND (dump last capture as hex, matching the historical format)
//--------------------------------------------------------------------------
void read_cmd(const char *args)
{
    printf("----------Start of ACQ----------\n");
    for (uint32_t i = 0; i < U4RK_RAW_SAMPLE_COUNT; ++i) {
        printf("%X,", ((capture_buf[i] >> 1) & 0x3FF));
    }
    printf("\n-----------End of ACQ-----------\n");
}

command_t command_list[] = {
    {"start acq", start_acq_cmd},
    {"write dac", write_dac_cmd},
    {"read", read_cmd},
    {"version", version_cmd},
    {"reboot-dfu", reboot_dfu_cmd},
#ifdef MUX
    {"write mux", max14866},
    {"set mux", max14866_set},
    {"clear mux", max14866_clear},
#endif
};

void process_command(char *input)
{
    char *command = strtok(input, " ");
    char *subcommand = strtok(NULL, " ");
    char *args = strtok(NULL, "");

    if (command != NULL && subcommand != NULL)
    {
        char full_command[50];
        snprintf(full_command, sizeof(full_command), "%s %s", command, subcommand);

        for (int i = 0; i < sizeof(command_list) / sizeof(command_t); i++)
        {
            if (strcmp(full_command, command_list[i].command_name) == 0)
            {
                if (args == NULL)
                {
                    args = "0";
                }
                command_list[i].func(args);
                return;
            }
        }
        printf("Unknown command: %s %s\n", command, subcommand);
    }
    else if (command != NULL)
    {
        for (int i = 0; i < sizeof(command_list) / sizeof(command_t); i++)
        {
            if (strcmp(command, command_list[i].command_name) == 0)
            {
                command_list[i].func(args);
                return;
            }
        }
        printf("Unknown command: %s\n", command);
    }
}

void read_input(char *buffer, int max_len)
{
    int index = 0;
    while (1)
    {
        char ch = getchar();
        if (ch == '\r' || ch == '\n')
        {
            buffer[index] = '\0';
            printf("\n");
            return;
        }
        else if (ch == 127 || ch == '\b')
        {
            if (index > 0)
            {
                index--;
                printf("\b \b");
            }
        }
        else if (ch >= 32 && ch <= 126)
        {
            if (index < max_len - 1)
            {
                buffer[index++] = ch;
                putchar(ch);
            }
        }
    }
}

//---------------------------------------------------------------------------
// MAIN FUNCTION
//---------------------------------------------------------------------------
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

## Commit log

2024-03-31 Hardware pieces
    [HV-BOARD-B_Cu.gbr, HV-BOARD-B_Mask.gbr, HV-BOARD-B_Paste.gbr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]
2024-10-21 New shell approach
    [PICO_ADC_Test.csv]
2024-10-29 v2 of hardware along with silkscreen
    [HV-BOARD-B_Cu.gbr, HV-BOARD-B_Mask.gbr, HV-BOARD-B_Paste.gbr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]
2024-11-07 Update of the VGA driver to use actual PINs from the VGA header
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2024-11-12 pulser+hv board together for prod
    [BOM-HV-BOARD - pannel.csv, BOM-panel.csv, BOM.csv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]
2024-11-28 Adding pnp files
    [PICO_ADC_Test-all-pos.csv, PICO_ADC_Test-pnp_bottom.gbr, PICO_ADC_Test-pnp_top.gbr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]
2025-11-11 Pulser update
    [HV-BOARD-B_Cu.gbr, HV-BOARD-B_Mask.gbr, HV-BOARD-B_Paste.gbr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]
2025-12-21 Update picO
    [BOM-MAX14866_PMOD.csv, BOM_PICO_ADC_Test.csv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]
2026-09-11 Add KiBot production-output script for hardware boards
    hardware/build.sh + jlcpcb.kibot.yaml generate JLCPCB-friendly outputs from
    a KiCad board into <board>/build_<vendor>/:
    - zipped gerbers + drill (production upload)
    - pick & place (CPL) and BOM CSVs in JLCPCB column format
    - schematic PDF and interactive HTML BOM
    - STEP model and top/bottom 3D PNG renders
    Notes:
    - PNG renders use `kicad-cli pcb render` directly, since KiBot's render_3d
    refuses the CLI backend on KiCad < 10.0.5 and its GUI fallback fails headless.
    - Output folder derives from the config basename (jlcpcb.kibot.yaml ->
    build_jlcpcb), so another vendor's *.kibot.yaml gets a parallel folder.
    - The build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
2026-09-12 cleanup of hardware
    [MAX14866_PMOD-B_Cu.gbl, MAX14866_PMOD-B_Mask.gbs, MAX14866_PMOD-B_Silkscreen.gbo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]
2026-09-12 hardware: render 3D by default, add fast fab-only path
    build.sh now produces the STEP + top/bottom PNG renders for every build
    group (folds the KiBot 'step' target into fab/production/docs and always
    runs render_pngs, gated by WITH_3D). Add a 'fab-fast' group that skips 3D
    for a ~2 s gerber-only turnaround. Regenerate the mux production artefacts
    (now including 3D/) and document the flow in docs/claude/hardware-build.md.
    Claude-Session: https://claude.ai/code/session_017o6Yde3mPZfWcQ7xwHRooG
    [MAX14866_PMOD-B_Cu.gbl, MAX14866_PMOD-B_Mask.gbs, MAX14866_PMOD-B_Silkscreen.gbo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]
2026-09-12 docs: add Getting Started guide, fix gain label, add open questions
    - README: remove stray character, mention RP2350, add Getting Started
    section with firmware flashing, Python setup, quick-start code,
    serial command table with parameter details, and signal chain diagram
    - ndt_acquisition.py: correct gain field label from [dB] to raw DAC
    value (0-1023); fix same error in label() and calibrate() plot title;
    add gain/pon/poff/damp parameter docs to from_probe() docstring
    - requirements-minimal.txt: add minimal install requirements (5 packages)
    alongside the existing full environment freeze
    - QUESTIONS.md: 14 open questions on firmware, hardware, Python library,
    and documentation fo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
    [ndt_acquisition.py]
2026-09-12 feat(python): add MUX command methods to match firmware
    Audit of firmware serial commands (firmware/main.c) against python/pic0rick
    found write/set/clear mux had no Python counterpart. Add write_mux(), set_mux(),
    and clear_mux() to Pic0rick. write_mux formats ints as hex to match the
    firmware's strtol base-16 parse.
    Discoveries (mux absent from high-level acquisition flow; undocumented MAX14866
    bit map) logged in docs/claude/TODO.md.
    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
2026-09-12 feat(firmware,python): version command + optional MUX + CI releases
    Firmware v0.1.0, Python library v0.1.0.
    Firmware:
    - Add version.yaml (A.B.C + changes) as single source of truth; CMake generates
    version.h; new 'version' CLI command prints version/changes/mux state.
    - Make the MAX14866 mux optional at compile time via -DMUX (default ON). Split
    the always-needed MCP4812 gain DAC out to max/dac.c so it survives -DMUX=OFF;
    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
2026-09-13 feat(firmware): version command reports board/hash/release + dual-version release notes
    Firmware v0.1.1.
    - version command now also prints board/chip (from PICO_BOARD), the git build
    hash (version_git.h, regenerated every build via cmake/git_version.cmake;
    -dirty when firmware/ has uncommitted changes), and the release URL derived
    from the git remote + fw-v<version> tag.
    - version.h gains FW_BOARD/FW_CHIP/FW_RELEASE_URL (configure-time); FW_GIT_HASH
    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
2026-09-13 feat(python): add Pic0rick.version() to parse firmware version command
    Python library v0.1.1.
    Sends 'version' to the firmware and parses the multi-line reply into a dict
    (version/changes/board/chip/mux/mux_enabled/build/release/raw). Prefix-based
    parsing tolerates REPL echo and the run> prompt. Lets a host confirm which
    firmware/board/mux build a connected device runs.
    Verified the parser against a simulated response; not run on live hardware.
    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
2026-09-13 feat(firmware): add reboot-dfu command (fw v0.1.2), verified on hardware
    Adds a reboot-dfu CLI command that calls reset_usb_boot(0,0) to reboot into the
    USB bootloader (BOOTSEL/UF2 mass storage), so successive builds can be flashed
    without pressing BOOTSEL. Links pico_bootrom.
    Flashed and tested on a connected RP2350A/Pico 2 W: version reports correctly and
    the flash -> run -> reboot-dfu -> BOOTSEL loop works. Hardware flashing/serial/DFU
    recipe documented in docs/claude/hardware-testing.md.
    On branch feature/unify-firmware-dsp (prerequisite tooling before the DSP merge).
    Claude-Session: https://claude.ai/code/session_01XkewDGP2kE9LC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
    [main.c]
2026-09-13 P0: bump Pico SDK 2.2.0 -> 2.3.0 (fw v0.1.3)
    First phase of the onboard-DSP unification. Bumps sdkVersion/picotoolVersion in
    firmware/CMakeLists.txt and the CI workflow pico-sdk ref to 2.3.0; toolchain kept
    at 14_2_Rel1 (the installed one; builds SDK 2.3.0 fine).
    All 4 variants build against SDK 2.3.0. Verified on hardware: flashed the rp2350
    build via the reboot-dfu loop and confirmed the board runs v0.1.3.
    On branch feature/unify-firmware-dsp.
    Claude-Session: https://claude.ai/code/session_01XkewDGP2kE9LCTpzmGf5CE
2026-09-13 P2: land onboard-DSP modules under firmware/dsp/ (fw v0.1.5)
    Copies the onboard_dsp sources into firmware/dsp/ (keeping u4rk_/U4RK_ names) and
    builds the USB-free compute/hardware set (dsp, pipeline, protocol, acquisition,
    spi1 dac) as a new p0rk_dsp static library, compiled only under -DDSP=ON. Wires
    acquisition.pio + pulser.pio headers and links CMSIS-DSP (cmsisdsp_p0rk).
    usb_transport.c / usb_descriptors.c / tusb_config.h are copied in-tree but not
    compiled yet: their TinyUSB device callbacks conflict with the stdio_usb REPL, so
    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
2026-09-13 P3: runnable DSP build with raw-TinyUSB command loop (fw v0.1.6)
    Adds firmware/main_dsp.c (from onboard_dsp main.c), selected in CMake under
    if(DSP): SDK stdio OFF, links p0rk_dsp + usb_transport/usb_descriptors +
    tinyusb_device. Adds version + reboot-dfu commands and, under -DMUX,
    write/set/clear mux (+ max14866_init at boot). Non-DSP builds keep the stdio
    main.c unchanged. Also adds the U4RK_CMSIS_DSP_VERSION compile define.
    In the DSP build the gain DAC is the spi1 driver in p0rk_dsp; the PIO DAC
    (max/dac.c) and mainline PIO ADC (adc/adc.c) are not compiled.
    Verified on RP2350A/Pico 2 W hardware (flashed via reboot-dfu): version, help and
    status return correctly over the raw-TinyUSB CDC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
    [main_dsp.c]
2026-09-13 P4a: two-length acquisition read_raw (8000) / read_fft (4096) (fw v0.1.7)
    Capture length is now per-mode instead of a fixed 4096: read_raw captures 8000
    raw ADC samples (no FFT), read_fft captures 4096 for the Hilbert envelope (the
    CMSIS arm_rfft_fast max). Per-job sample_count threaded through u4rk.h /
    acquisition.c / dsp.c / pipeline.c; raw buffers sized to 8000; frame header
    sample_count makes frames self-describing (max payload unchanged: 4096 floats >
    8000 u16).
    Verified on RP2350A hardware: read_raw -> 16064 B frame (64+8000x u16), read_fft
    -> 16448 B (64+4096x float); header sample_count correct. Default builds
    unchanged.
    On branch feature/unify-firmware-dsp.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
    [acquisition.c, main_dsp.c, u4rk.h]
2026-09-13 P4b: unify hardware drivers into firmware/hw (fw v0.1.8)
    Both the stdio and DSP builds now share one acquisition + pulser + spi1 DAC.
    Moved acquisition/pulser/dac/u4rk.h from firmware/dsp to a shared firmware/hw
    (so the stdio build can use them without colliding with SDK stdio's TinyUSB
    tusb_config.h). Rewrote the stdio main.c to drive the shared pulser/DAC:
    start acq (8000-sample capture), write dac (spi1), read. Retired firmware/adc/
    (PIO pulser/ADC) and firmware/max/dac.c (PIO DAC).
    Verified on RP2350A hardware (stdio build): write dac 500 -> dac=500;
    start acq 200 200 2000 -> 8000 samples captured (no timeout); read -> ~8000 sane
    ADC samples. DSP build + all 4 default variants build.
    O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
    [acquisition.c, adc.c, adc.h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]
2026-09-13 P5: DSP-build host protocol in python (py v0.1.2)
    Add pic0rick/dsp.py (ported from experiments/onboard_dsp/tools): FrameReader +
    CRC32, Frame/FrameHeader, alaw_decode, parse_status. Length-agnostic - payload
    size is derived from the header sample_count so read_raw (8000) and read_fft
    (4096) both parse. Add Pic0rick.status()/capture()/read_fft()/read_raw().
    Dropped the old EXPECTED_FIRMWARE=='1.6' hard gate; the host now parses whatever
    firmware=A.B.C the board reports.
    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
2026-09-13 P7: retire experiments/onboard_dsp (py v0.1.3)
    The onboard_dsp DSP firmware now lives only in the mainline firmware/ tree
    (-DDSP), so remove experiments/ entirely (firmware, tools, notebook, captures).
    Keep the durable format spec: understanding_figures.md -> docs/dsp_output_formats.md
    (pointed at pic0rick.dsp). Drop test_guide.md, DSP_Tests.ipynb and
    tools/pic0rick_capture.py (coupled to the removed CLI, superseded by pic0rick.dsp;
    rewrite logged in TODO). Fix all references (CLAUDE.md, docs/claude notes,
    python/Readme, dsp.py) and rewrite onboard-dsp-firmware.md as a pointer.
    check-links: no genuine local breaks (flagged refs are regex strings / vendored
    CMSIS-DSP). One firmware, one host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
    [acquisition.c, dac.c, dsp.py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]
2026-09-13 fix(firmware): pulser echo regression - bipolar pulse then damp (fw v0.1.10)
    Echoes worked on stdio v0.1.0 but broke after the unification. Root cause: not
    OE (that's active-high, matching the pulser board's AND-gate) but the pulse
    waveform. P4b adopted the shared pulser.pio, which put the PDAMP damp phase
    BETWEEN the negative and positive drive; with the default long damp this splits
    the bipolar excitation into two weak spikes -> no echo.
    Reorder hw/acquisition.c queue_pulse so both drive polarities fire back-to-back
    and PDAMP damping comes last, as in v0.1.0 (and standard practice). No PIO
    change; applies to both stdio and DSP builds (shared firmware/hw).
    Verified on RP2350A: armed trans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
    [acquisition.c]
2026-09-13 fix(firmware): MUX/pulser PIO1 SM conflict - restores echoes (fw v0.1.11)
    The real no-echo cause: max14866_init() hardcoded PIO1 sm0, but the shared
    pulser (u4rk_acquisition_init) claims PIO1 sm0/sm1 first. On MUX builds the mux
    init clobbered the pulser drive SM, so no transmit pulse fired (only crosstalk)
    and no echo returned. In v0.1.0/0.1.1 there was no clash (old pulser on PIO0);
    the unification moved the pulser to PIO1. Fix: claim an unused SM.
    Verified on hardware with the user's piezo: mux build echo var[2000:3000] went
    0.4 -> ~52k at gain 300 (matches the v0.1.1 baseline 60k), echo structure and
    gain-scaling confirmed. The v0.1.10 damp-reorder is also kept.
    On branch feature/unify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
    [max14866.c]
2026-09-13 docs: start docs/fw_history convention (maintainer-only .uf2 baselines)
    Add docs/fw_history/README.md: purpose, naming (fw<A.B.C>-<board>-<options>.uf2),
    the fw0.1.1-RP2350-muxenabled baseline entry, and links to example_simple.ipynb.
    Record the rule that only the maintainer adds .uf2 there (Claude never
    adds/commits .uf2 to that folder; may edit the README and flash baselines) in
    docs/claude/README.md and memory.
    The baseline .uf2 and example_simple.ipynb were committed by the maintainer.
    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
2026-09-14 feat(python): example_dsp.ipynb - arm-from-start, A-law, self-test, file saving (py v0.1.7)
    Reworked the DSP notebook per request: pulser armed from the start; A-law capture
    + dsp.alaw_decode overlaid on the Hilbert envelope; DSP self-test (21 vectors,
    named cases); pulser-order check; and per-capture file saving to
    captures/<name>/ (<payload>.npy + header.json + status.txt), bringing back the
    richer steps from the old onboard_dsp DSP_Tests.ipynb. All Pico text replies +
    per-stage DSP us times shown. Added dsp.SELFTEST_NAMES; gitignore captures/.
    Verified by executing the notebook via nbconvert on the RP2350A DSP mux build
    (pulser armed): raw/envelope/alaw captured + saved, self-test 21 fra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
    [dsp.py]
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2026-09-14 feat(hardware): add panel_adc_pulser_hv board to build.sh
    Register the new 3_in_1_Panel board (panel_adc_pulser_hv) in the
    build.sh BOARDS registry and add its JLCPCB production outputs
    (gerbers, drill, CPL/BOM, schematic PDF, iBOM, 3D STEP + renders).
    Claude-Session: https://claude.ai/code/session_01QUWt9AXKNLq58U2DqGTPyR
    [3_in_1_Panel-JLCPCB-BOM.csv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]
2026-09-14 docs(readme): update Python/CLI usage for the unified firmware + add repo layout
    Quick start now uses the DSP-build API (set_gain/configure_pulse/arm_pulser/
    read_raw) since the stdio dac/pulse_adc_trigger/read commands do not transmit on
    the DSP build the board runs; note the stdio alternative. Relabel the serial
    command table as the stdio build and fix the mux rows; expand the DSP-build
    section with its commands + Pic0rick helpers. Fix pulser pins in the signal chain
    (GPIO11/12 + GPIO16/17, MD1213). Add a Repository layout table.
    Verified all README Python references against the code.
    Claude-Session: https://claude.ai/code/session_0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
